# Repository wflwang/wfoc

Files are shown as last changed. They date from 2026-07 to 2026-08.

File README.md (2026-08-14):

# WFOC - 开源低成本高性能FOC电调





WFOC (WFL FOC) 是一款面向开源社区的低成本高性能无刷直流电机 FOC 控制器。项目参考 STM32 FOC 驱动、VESC 开源代码和 SimpleFOC，在国产 CIU32F003x5 (ARM Cortex-M0+) 上实现了完整的电机控制固件。

- 开源地址: https://github.com/wflwang/wfoc.git
- 邮箱: B5106D@Outlook.com

## 项目特点

- **低成本**: 采用国产 MCU (CIU32F003x5) 和 FD6288 栅极驱动，BOM 成本低
- **高性能**: 中断内全定点 Q16.16 运算（无浮点），20kHz PWM 电流环
- **双模式**: 同时支持 FOC 矢量控制和 BLDC 六步换相，可通过 `comm_mode` 配置切换
- **多观测器**: 滑模观测器 (SMO)、MXLEMMA 全阶观测器、MXV_Lambda 补偿、高频注入 (HFI)
- **VESC 风格协议**: 二进制 UART 协议，支持参数读写、实时遥测、高速流式打印
- **开源**: 硬件 (CERN-OHL-S v2) 和软件 (MIT) 全部开源

## 硬件架构

### 核心器件

| 器件 | 型号 | 封装 | 功能 |
|---|---|---|---|
| MCU | CIU32F003x5 | QFN-20 | 32位 ARM Cortex-M0+, 24MHz, 32KB Flash |
| 栅极驱动 | FD6288 | TSSOP-20 | 三相半桥驱动，内置自举二极管 |
| 运算放大器 | XOPA2333 | - | 2通道电流采样放大 |
| MOSFET | N-MOS | TO-252-2 | 3上 + 3下功率开关管 |

### 硬件特性

- **电源输入**: 10-48V DC
- **持续电流**: 20A（峰值 60A）
- **PWM 频率**: 8kHz-20kHz 可调（默认 20kHz）
- **电流采样**: 2路下桥臂电阻采样 (0.005R + 20x 运放)
- **通信接口**: UART (115200~921600) / PPM
- **保护功能**: 过流、过压、欠压、过温保护
- **调试接口**: SWD

### 引脚映射

引脚定义见 [board_config.h](software/config/board_config.h)，摘要：

| 功能 | 引脚 | 说明 |
|---|---|---|
| UART TX/RX | PC0 / PB5 | 串口通信 |
| PWM A 高/低 | PB2 / PB3 | A相上下管 |
| PWM B 高/低 | PC1 / PB7 | B相上下管 |
| PWM C 高/低 | PA1 / PA0 | C相上下管 |
| 电流采样 A/B | PB0 / PB1 | ADC CH0/CH1 |
| 相电压 U/V/W | PA3 / PA4 / PA5 | ADC CH3/CH4/CH5 |
| 母线电压 | PA7 | ADC CH7 |
| 温度 | PA6 | ADC CH6 |
| PPM 输入 | PB4 | TIM2 输入捕获 |

## 软件架构

### 目录结构

```
software/
├── main.c                  # 主程序入口（初始化与主循环）
├── interrupts.c            # 中断服务（ADC1 FOC环 / UART / PPM / SysTick）
├── Makefile                # 编译脚本
│
├── app/                    # 应用层
│   ├── app.c               # 状态机、安全监督、斜坡控制
│   ├── app_uart.c          # UART控制接口（VESC风格协议、实时遥测）
│   ├── app_ppm.c           # PPM脉冲解码
│   └── app_sound.c         # 电机发声
│
├── motor/                  # 电机控制核心
│   ├── mcpwm.c             # PWM后端桥接（duty/current/speed/position）
│   ├── observer.c          # 观测器（SMO / MXLEMMA / HFI + PLL）
│   ├── bldc.c              # BLDC六步换相（多种反电动势检测）
│   └── encoder.c           # 编码器接口
│
├── driver/mcu/             # MCU外设驱动
│   ├── adc.c               # ADC驱动（DMA多通道，偏置校准）
│   ├── pwm.c               # PWM驱动（TIM1三相中心对齐）
│   ├── uart.c              # UART驱动（环形缓冲收发）
│   ├── timer.c             # 定时器（PPM捕获/看门狗）
│   ├── gpio.c              # GPIO配置
│   ├── mcu_init.c          # 系统初始化（时钟/SysTick）
│   └── ciu32f003x.h        # MCU寄存器定义
│
├── conf/                   # 配置系统
│   ├── datatypes.h         # 核心数据类型（motor_state_t / mc_configuration_t）
│   ├── conf_default.c      # 默认参数
│   └── conf_general.c      # 配置管理（持久化接口）
│
├── config/                 # 编译时配置
│   ├── board_config.h      # 板级引脚映射与硬件参数
│   ├── hwconf.h            # 硬件目标选择（make HW=WFoc_V1）
│   └── fw_version.h        # 固件版本与功能开关
│
├── packet/                 # 通信协议
│   └── packet.c            # VESC风格帧封装（CRC16/CCITT）
│
├── startup/                # 启动文件
│   ├── linker.ld           # 链接脚本
│   └── startup_ciu32f003x.s# 启动汇编
│
└── util/                   # 工具库
    └── fixedpoint.c        # 定点数数学库（Q16.16, 三角函数, PI/PID, 陷波滤波）
```

### 数据流

```
ADC1 ISR (20kHz) ──► 电流采样 ──► Clarke ──► 观测器(角度/转速)
                                       │              │
                                       ▼              ▼
                                     Park ──► PI电流环 ──► 逆Park
                                                          │
                                                       SVPWM ──► TIM1 PWM
                                                          │
应用层 (main loop)                                        │
  app_process() ──► mcpwm_set_*() ──► foc_state.iq_set ───┘
  app_uart_process() ──► 遥测发送 ──► UART
```

### 核心功能实现状态

- [x] FOC 矢量控制（Clarke/Park/SVPWM/电流环PI）
- [x] BLDC 六步换相（ADC/比较器/过零检测 + 参数自学习）
- [x] 观测器（SMO / MXLEMMA / HFI + PLL 锁相环）
- [x] 定点数数学库（Q16.16，中断内无浮点）
- [x] VESC 风格 UART 协议（参数读写、固件版本、终端命令）
- [x] 实时遥测（3相电流、3相电压、转速、d/q轴等）
- [x] 高速流式打印（COMM_GET_VALUES_SELECTIVE + streaming）
- [x] ADC 偏置自校准（上电自动测量零电流偏移）
- [x] 安全监督（过流/过压/欠压/过温保护 + 故障状态机）
- [x] PPM 输入控制
- [x] 电机发声功能
- [ ] 速度闭环 PI（当前为前馈，参数已预留）
- [ ] 位置闭环控制
- [ ] 弱磁控制 / 过调制 / 陷波滤波（框架已建，待接入电流环）
- [ ] Flash 参数持久化（接口已定义，存储待实现）

## 编译环境

### 工具链安装

固件目标为 ARM Cortex-M0+，需要 `arm-none-eabi-gcc` 交叉编译工具链。

**Windows:**
1. 下载 [GNU Arm Embedded Toolchain](https://developer.arm.com/tools-and-software/open-source-software/developer-tools/gnu-toolchain/gnu-rm/downloads)
2. 解压并将 `bin` 目录加入系统 `PATH`
3. 安装 [Make for Windows](http://gnuwin32.sourceforge.net/packages/make.htm) 或使用 MSYS2

**Linux (Ubuntu/Debian):**
```bash
sudo apt install gcc-arm-none-eabi binutils-arm-none-eabi openocd
```

**macOS (Homebrew):**
```bash
brew install arm-gcc-bin openocd
```

### 验证工具链

```bash
arm-none-eabi-gcc --version    # 需要 10.x 或以上
arm-none-eabi-objcopy --version
openocd --version              # 烧录用
```

### 仿真环境（可选）

仿真在 PC 上运行，验证 FOC 定点算法，只需系统自带 GCC：

```bash
gcc --version    # Windows 可用 MinGW / MSYS2 的 gcc
```

## 编译步骤

### 编译固件

```bash
cd software
make              # 默认硬件目标 WFoc_V1
```

指定硬件目标与优化：
```bash
make HW=WFoc_V1   # 选择硬件版本（当前支持 V1）
make clean         # 清理构建产物
make size          # 查看 Flash/RAM 占用
make info          # 打印源文件列表和编译选项
```

编译成功后输出：
- `build/wfoc.elf` - ELF 可执行文件
- `build/wfoc.hex` - Intel HEX（烧录用）
- `build/wfoc.bin` - 二进制文件
- `build/wfoc.map` - 链接映射表

### 烧录固件

通过 ST-Link / J-Link + OpenOCD 烧录：
```bash
make flash        # 调用 openocd 烧录 build/wfoc.hex
```

也可手动烧录：
```bash
openocd -f interface/stlink.cfg -f target/ciu32f003x.cfg \
    -c "program build/wfoc.hex verify reset exit 0x08000000"
```

### 运行仿真

```bash
# Windows / Linux / macOS 均可
gcc -O2 -o simulation/sim_foc.exe simulation/sim_main.c software/util/fixedpoint.c -lm
./simulation/sim_foc.exe        # Linux/macOS
.\simulation\sim_foc.exe        # Windows PowerShell
```

仿真说明：
- 仿真使用**真实的定点数库** (`fixedpoint.c`)，与固件 ISR 完全相同的 Q16.16 运算
- `sim_main.c` 顶部 `SIM_USE_PERFECT_ANGLE` 开关：
  - `1` = 完美角度（验证 FOC 电流环本身），电机应加速到 400+ RPM
  - `0` = 观测器模式（验证 FOC + 观测器），验证角度估算

## 通信协议

### UART 接口

- 默认波特率: 115200（可通过参数调整为 921600 以支持高速打印）
- 格式: 8N1
- 协议: VESC 风格二进制帧

### 帧格式

```
短帧 (<256字节):  [0x02] [len] [payload...] [crc_hi] [crc_lo] [0x03]
长帧 (>=256字节): [0x03] [len_hi] [len_lo] [payload...] [crc_hi] [crc_lo] [0x03]
```
- `payload` = `[command] [data...]`
- CRC: CRC-16/CCITT (poly 0x1021, init 0xFFFF)

### 支持的命令

| 命令 | 名称 | 说明 |
|---|---|---|
| 0 | COMM_FW_VERSION | 获取固件版本与硬件名称 |
| 2 | COMM_GET_VALUES | 获取完整实时数据（含3相电流/电压/转速） |
| 4 | COMM_SET_DUTY | 设置占空比 (x1e5) |
| 5 | COMM_SET_CURRENT | 设置电流 (x1e3) |
| 6 | COMM_SET_CURRENT_BRAKE | 制动电流 (x1e3) |
| 7 | COMM_SET_RPM | 设置转速 ERPM |
| 8 | COMM_SET_POS | 设置位置 (x1e6) |
| 11 | COMM_GET_MCCONF | 读取电机配置 |
| 12 | COMM_SET_MCCONF | 写入电机配置 |
| 13/14 | COMM_GET/SET_APPCONF | 读取/写入应用配置 |
| 15 | COMM_DETECT_MOTOR_PARAM | 电机参数检测 |
| 17 | COMM_TERMINAL_CMD | 终端命令 (help/stop/restart/alive) |
| 18 | COMM_GET_VALUES_SELECTIVE | 高速选择性遥测（见下） |

### 实时遥测与高速打印

**完整遥测 (COMM_GET_VALUES)**：请求一次返回一帧，包含温度、3相电流、3相电压、d/q轴、占空比、转速、位置、母线电压、功率、故障码等。

**高速选择性遥测 (COMM_GET_VALUES_SELECTIVE)**：

上位机发送 `[mask:u32][rate_ms:u16]`，固件按位掩码只打包需要的字段，大幅减小数据包。`rate_ms > 0` 时开启**主动流式发送**（streaming），固件在主循环按设定间隔自动发送，无需反复请求。

字段掩码位定义（见 [datatypes.h](software/conf/datatypes.h)）：
```
bit 0-2:   IA / IB / IC     (3相电流)
bit 3-5:   VA / VB / VC     (3相电压)
bit 6-9:   ID / IQ / VD / VQ (d/q轴电流电压)
bit 10:    DUTY
bit 11:    SPEED (ERPM)
bit 12:    POSITION (rad)
bit 13:    VBUS
bit 14-15: TEMP_MOS / TEMP_MOT
bit 16:    POWER
```

示例：以 1ms 速率只打印 3相电流 + 3相电压 + 转速：
```
mask = IA|IB|IC|VA|VB|VC|SPEED = 0x208F
发送: COMM_GET_VALUES_SELECTIVE + [0x8F,0x20,0x00,0x00] + [0x01,0x00]
```

**实现原理**（高速打印关键）：
1. ADC 中断 (20kHz) 只采集数据存入 `motor_state` 变量，**不在中断中发串口**
2. 主循环中一次性组装数据包通过 UART 发送
3. streaming 模式避免请求-响应往返延迟
4. 提高波特率 (921600) 可进一步缩短发送时间

## 配置与调参

所有电机参数可通过 UART 在线调整（COMM_GET/SET_MCCONF），参数定义见 [datatypes.h](software/conf/datatypes.h) 的 `mc_configuration_t`，默认值见 [conf_default.c](software/conf/conf_default.c)。

关键参数：
- `comm_mode`: 0=FOC, 1=BLDC
- `observer_type`: 0=无, 1=SMO, 2=MXLEMMA, 3=MXV_Lambda, 4=HFI
- `motor_r / motor_l / motor_flux_linkage / motor_poles`: 电机参数
- `foc_current_kp / ki`: 电流环 PI 增益
- `foc_speed_kp / ki`: 速度环 PI 增益
- `l_max_current / l_max_speed / l_max_duty`: 限幅

## 贡献指南

欢迎任何形式的贡献！请遵循以下步骤：

1. Fork 本仓库
2. 创建功能分支 (`git checkout -b feature/your-feature`)
3. 提交代码 (`git commit -am 'Add some feature'`)
4. 推送到分支 (`git push origin feature/your-feature`)
5. 创建 Pull Request

## 许可证

本项目采用双重许可证：

| 部分 | 许可证 | 文件 |
|---|---|---|
| 软件代码 | MIT License | [LICENSE](LICENSE) |
| 硬件设计文件 | CERN-OHL-S v2 | [LICENSE-HARDWARE](LICENSE-HARDWARE) |

## 致谢

感谢以下开源项目的启发和参考：

- [VESC](https://github.com/vedderb/bldc) - BLDC 开源电调
- [SimpleFOC](https://github.com/simplefoc/Arduino-FOC) - 简易 FOC 库

## 联系方式

- 邮箱: B5106D@Outlook.com
- GitHub Issues: [提交 Issue](https://github.com/wflwang/wfoc/issues)

---

**免责声明**: 本项目仅供学习和研究使用。使用本项目造成的任何损失，作者不承担责任。请在使用前充分测试并确保安全。

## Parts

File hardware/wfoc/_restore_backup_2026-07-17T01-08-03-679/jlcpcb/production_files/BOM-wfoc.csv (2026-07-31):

Comment | Designator | Footprint | LCSC | Quantity
NMOS | Q1 | TO-252-2 |  | 1
105 | C5 | C_0603_1608Metric |  | 1
10R | R23 | R_0603_1608Metric |  | 1
100R | R13 | R_0603_1608Metric |  | 1
NMOS | Q3 | TO-252-2 |  | 1
10K | R32 | R_0603_1608Metric |  | 1
10K | R29 | R_0603_1608Metric |  | 1
NMOS | Q2 | TO-252-2 |  | 1
10R | R24 | R_0603_1608Metric |  | 1
10K | R28 | R_0603_1608Metric |  | 1
10K | R30 | R_0603_1608Metric |  | 1
20K 1% | R15 | R_0603_1608Metric |  | 1
104 | C7 | C_0603_1608Metric |  | 1
2.2K | R20 | R_0603_1608Metric |  | 1
103 | C19 | C_0603_1608Metric |  | 1
10R | R27 | R_0603_1608Metric |  | 1
10K 1% | R9 | R_0603_1608Metric |  | 1
10K | R44 | R_0402_1005Metric |  | 1
2K | R38 | R_0402_1005Metric |  | 1
0.1R | R18 | R_1206_3216Metric |  | 1
10R | R25 | R_0603_1608Metric |  | 1
104 | C14 | C_0603_1608Metric |  | 1
105 X7R | C17 | C_0603_1608Metric |  | 1
4.7K | R47 | R_0402_1005Metric |  | 1
47K | R40 | R_0805_2012Metric |  | 1
4.7K | R45 | R_0402_1005Metric |  | 1
10K | R33 | R_0603_1608Metric |  | 1
10K | R31 | R_0603_1608Metric |  | 1
20K 1% | R11 | R_0603_1608Metric |  | 1
47uH GSM0650-470-M | L1 | L_7.5x6.6mm |  | 1
470K | R17 | R_0603_1608Metric |  | 1
47K | R42 | R_0603_1608Metric |  | 1
104 | C6 | C_0603_1608Metric |  | 1
106 | C12 | C_0805_2012Metric |  | 1
20K 1% | R16 | R_0603_1608Metric |  | 1
10R | R26 | R_0603_1608Metric |  | 1
10R | R22 | R_0603_1608Metric |  | 1
470uf 80V | C9 | CP_Elec_10x12.5 |  | 1
2K | R36 | R_0402_1005Metric |  | 1
104 | C10 | C_0603_1608Metric |  | 1
100R | R14 | R_0603_1608Metric |  | 1
20K 1% | R12 | R_0603_1608Metric |  | 1
5819 | D1 | D_1206_3216Metric_Pad1.42x1.75mm_HandSolder |  | 1
TSSOP20 | U3 | TSSOP-20_4.4x6.5mm_P0.65mm |  | 1
2K | R37 | R_0402_1005Metric |  | 1
102 | C4 | C_0603_1608Metric |  | 1
20K | R19 | R_0603_1608Metric |  | 1
47K | R41 | R_0603_1608Metric |  | 1
102 | C3 | C_0603_1608Metric |  | 1
105 X7R | C16 | C_0603_1608Metric |  | 1
47K | R43 | R_0603_1608Metric |  | 1
103 | C20 | C_0603_1608Metric |  | 1
470uf 20V | C11 | CP_Radial_D10.0mm_P5.00mm_P7.50mm |  | 1
10R | R21 | R_0603_1608Metric |  | 1
2K | R35 | R_0603_1608Metric |  | 1
XOPA2333 | U2 | SOP-8_3.9x4.9mm_P1.27mm |  | 1
10K 1% | R7 | R_0603_1608Metric |  | 1
106 | C13 | C_0805_2012Metric |  | 1
~ | U1 | QFN-20-1EP_3x3mm_P0.4mm_EP1.5x1.5mm |  | 1
104 | C8 | C_0603_1608Metric |  | 1
6209 | U4 | SOT-23 |  | 1
105 X7R | C18 | C_0603_1608Metric |  | 1
4.7K | R46 | R_0402_1005Metric |  | 1
10uf 25V | C15 | C_0603_1608Metric |  | 1
10K NTC 4390K | TH1 | R_0603_1608Metric |  | 1
NMOS | Q5 | TO-252-2 |  | 1
0.005R 1% |  | R_2512_6332Metric |  | 0
0.005R 1% |  | R_2512_6332Metric |  | 0
NMOS | Q6 | TO-252-2 |  | 1
1K 1% | R10 | R_0603_1608Metric |  | 1
1K 1% | R5 | R_0603_1608Metric |  | 1
1K 1% | R8 | R_0603_1608Metric |  | 1
NMOS | Q4 | TO-252-2 |  | 1
1K 1% | R3 | R_0603_1608Metric |  | 1
0.005R 1% |  | R_2512_6332Metric |  | 0
0.005R 1% |  | R_2512_6332Metric |  | 0

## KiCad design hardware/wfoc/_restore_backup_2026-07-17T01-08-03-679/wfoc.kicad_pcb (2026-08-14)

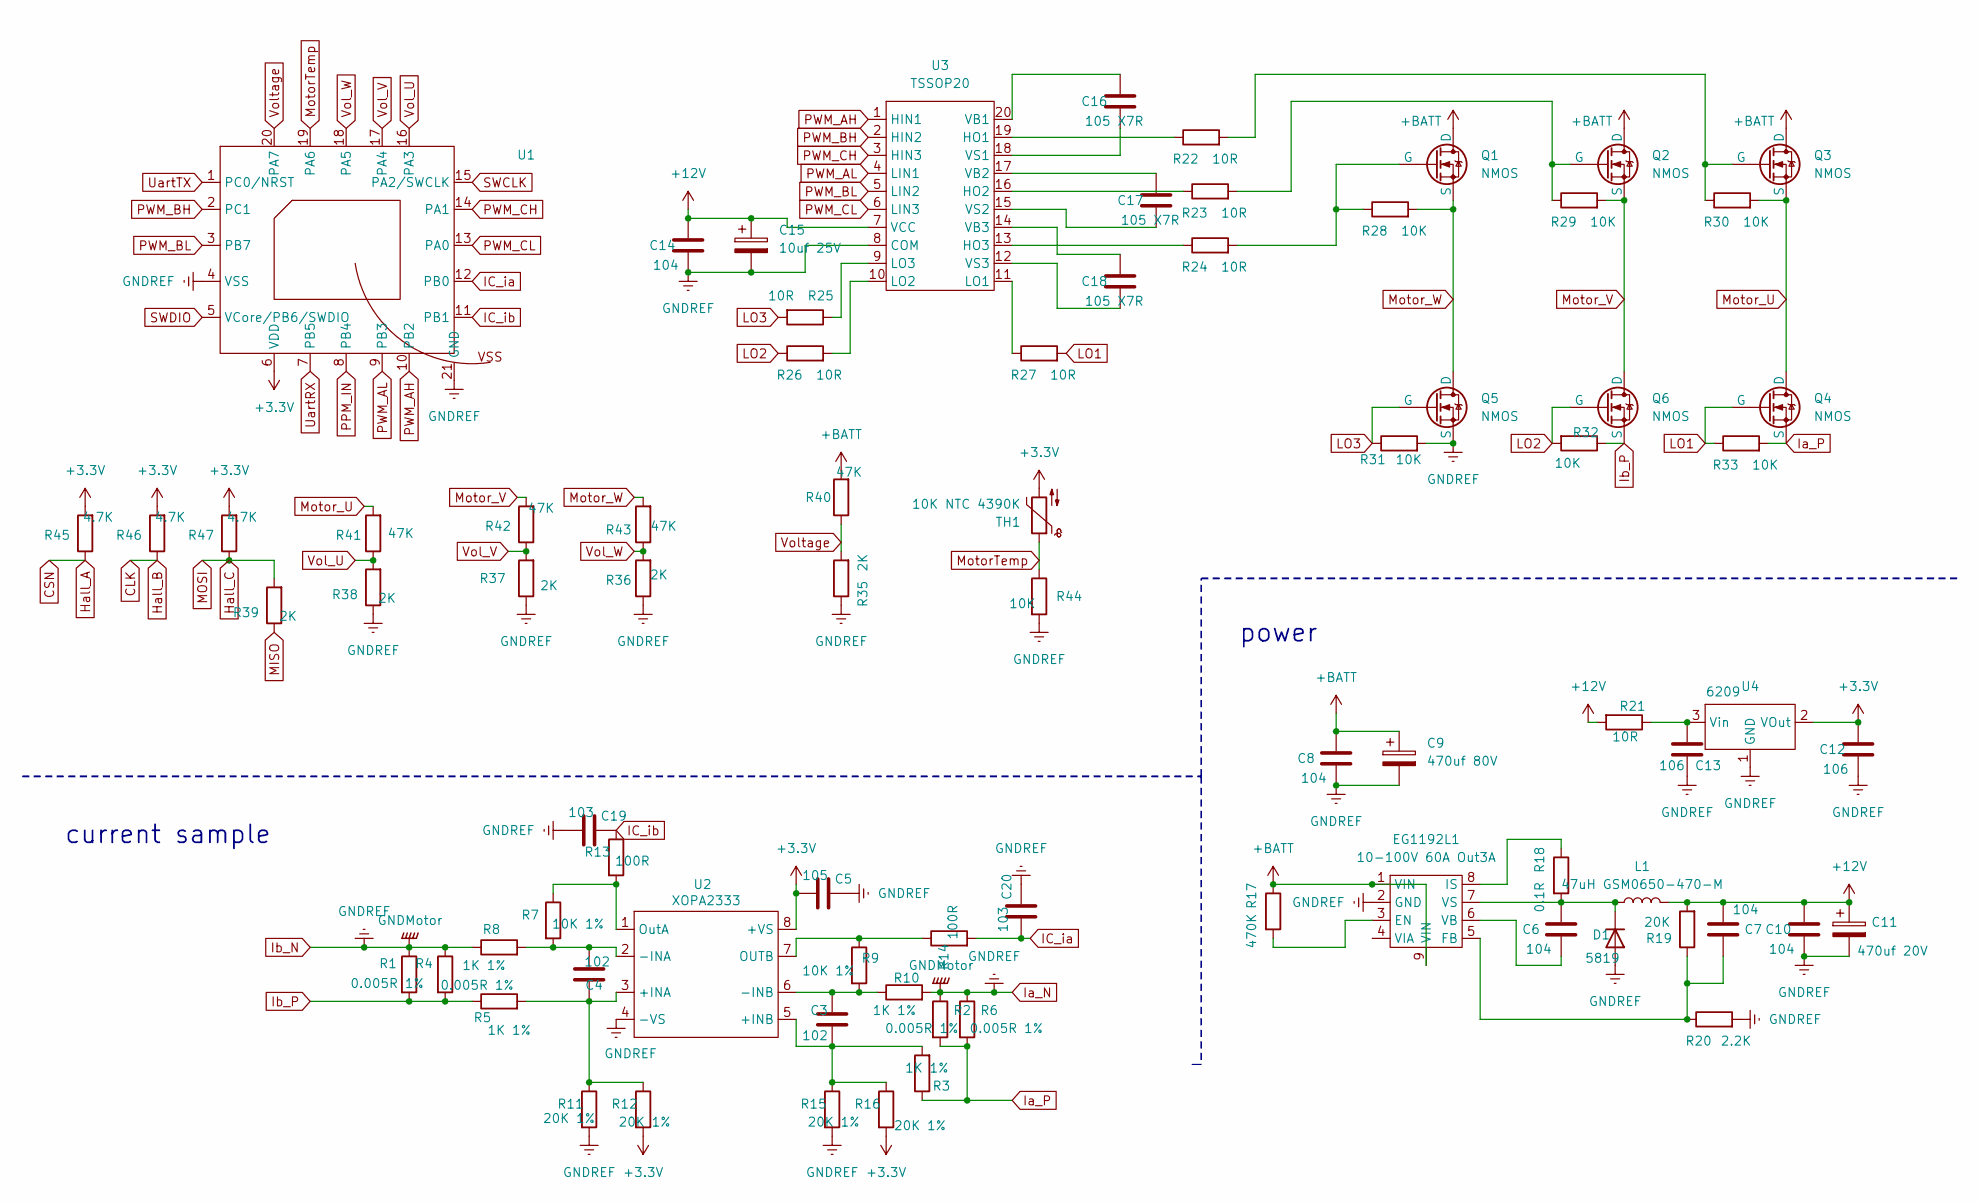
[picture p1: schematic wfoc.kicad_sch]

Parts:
C3, C4: 102; C_0603_1608Metric
C5: 105; C_0603_1608Metric
C6, C7, C8, C10, C14: 104; C_0603_1608Metric
C9: 470uf 80V; CP_Radial_D10.0mm_P7.50mm
C11: 470uf 20V; CP_Radial_D10.0mm_P7.50mm
C12, C13: 106; C_0805_2012Metric
C15: 10uf 25V; C_0603_1608Metric
C16, C17, C18: 105 X7R; C_0603_1608Metric
C19, C20: 103; C_0603_1608Metric
D1: 5819; D_1206_3216Metric_Pad1.42x1.75mm_HandSolder
EG1192L1: 10-100V 60A Out3A; SOP-8-1EP_6.0x4.9mm_P1.27mm_EP2.4x3.3mm
L1: 47uH GSM0650-470-M; L_7.5x6.6mm
Q1, Q2, Q3, Q4, Q5, Q6: NMOS; TO-252-2
R1, R2, R4, R6: 0.005R 1%; R_2512_6332Metric
R3, R5, R8, R10: 1K 1%; R_0603_1608Metric
R7, R9: 10K 1%; R_0603_1608Metric
R11, R12, R15, R16: 20K 1%; R_0603_1608Metric
R13, R14: 100R; R_0603_1608Metric
R17: 470K; R_0603_1608Metric
R18: 0.1R; R_1206_3216Metric
R19: 20K; R_0603_1608Metric
R20: 2.2K; R_0603_1608Metric
R21, R22, R23, R24, R25, R26, R27: 10R; R_0603_1608Metric
R28, R29, R30, R31, R32, R33: 10K; R_0603_1608Metric
R35: 2K; R_0603_1608Metric
R36, R37, R38, R39: 2K; R_0402_1005Metric
R40: 47K; R_0805_2012Metric
R41, R42, R43: 47K; R_0603_1608Metric
R44: 10K; R_0402_1005Metric
R45, R46, R47: 4.7K; R_0603_1608Metric
TH1: 10K NTC 4390K; R_0603_1608Metric
U1: QFN-20-1EP_3x3mm_P0.4mm_EP1.5x1.5mm
U2: XOPA2333; SOP-8_3.9x4.9mm_P1.27mm
U3: TSSOP20; TSSOP-20_4.4x6.5mm_P0.65mm
U4: 6209; SOT-23

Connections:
+3.3V: C5.1, C12.2, R12.2, R16.2, R45.2, R46.2, R47.2, TH1.2, U1.6 (VDD), U2.8 (+VS), U4.2 (VOut)
+12V: C7.1, C10.2, C11.1, C14.2, C15.1, L1.2, R19.2, R21.2, U3.7 (VCC)
+BATT: C8.2, C9.1, EG1192L1.1 (VIN), EG1192L1.9 (VIN), Q1.2 (D), Q2.2 (D), Q3.2 (D), R17.1, R40.2; also elsewhere on the board
IC_ia: C20.1, R14.2, U1.12 (PB0)
IC_ib: C19.2, R13.1, U1.11 (PB1)
Ia_N: C5.2, C8.1, C9.2, C10.1, C11.2, C12.1, C13.1, C14.1, C15.2, C19.1, C20.2, D1.2 (A), EG1192L1.2 (GND), Q5.3 (S), R1.1, R2.1, R4.1, R6.1, R8.1, R10.2, R11.2, R15.2, R20.2, R31.2, R35.1, R36.1, R37.1, R38.1, R44.2, U1.4 (VSS), U1.21 (GND), U2.4 (-VS), U3.8 (COM), U4.1 (GND); also elsewhere on the board
Ia_P: Q4.3 (S), R2.2, R3.1, R6.2, R33.2
Ib_P: Q6.3 (S), R1.2, R4.2, R5.1, R32.1
LO1: Q4.1 (G), R27.2, R33.1
LO2: Q6.1 (G), R26.1, R32.2
LO3: Q5.1 (G), R25.2, R31.1
MotorTemp: R44.1, TH1.1, U1.19 (PA6)
Motor_U: Q3.3 (S), Q4.2 (D), R30.2, R41.2
Motor_V: Q2.3 (S), Q6.2 (D), R29.2, R42.2
Motor_W: Q1.3 (S), Q5.2 (D), R28.2, R43.2
unnamed: C6.2, D1.1 (K), EG1192L1.7 (VS), L1.1, R18.2
unnamed: EG1192L1.3 (EN), R17.2
unnamed: C7.2, EG1192L1.5 (FB), R19.1, R20.1
unnamed: EG1192L1.8 (IS), R18.1
unnamed: C6.1, EG1192L1.6 (VB)
unnamed: Q1.1 (G), R24.2, R28.1
unnamed: Q2.1 (G), R23.2, R29.1
unnamed: Q3.1 (G), R22.2, R30.1
unnamed: C4.2, R5.2, R11.1, R12.1, U2.3 (+INA)
unnamed: C3.2, R3.2, R15.1, R16.1, U2.5 (+INB)
unnamed: C4.1, R7.2, R8.2, U2.2 (-INA)
unnamed: C3.1, R9.2, R10.1, U2.6 (-INB)
unnamed: R9.1, R14.1, U2.7 (OUTB)
unnamed: R7.1, R13.2, U2.1 (OutA)
unnamed: R22.1, U3.19 (HO1)
unnamed: R23.1, U3.16 (HO2)
unnamed: R24.1, U3.13 (HO3)
unnamed: R27.1, U3.11 (LO1)
unnamed: R26.2, U3.10 (LO2)
unnamed: R25.1, U3.9 (LO3)
unnamed: C16.2, U3.20 (VB1)
unnamed: C17.2, U3.17 (VB2)
unnamed: C18.2, U3.14 (VB3)
unnamed: C16.1, U3.18 (VS1)
unnamed: C17.1, U3.15 (VS2)
unnamed: C18.1, U3.12 (VS3)
unnamed: C13.2, R21.1, U4.3 (Vin)
PPM_IN: U1.8 (PB4)
PWM_AH: U1.10 (PB2), U3.1 (HIN1)
PWM_AL: U1.9 (PB3), U3.4 (LIN1)
PWM_BH: U1.2 (PC1), U3.2 (HIN2)
PWM_BL: U1.3 (PB7), U3.5 (LIN2)
PWM_CH: U1.14 (PA1), U3.3 (HIN3)
PWM_CL: U1.13 (PA0), U3.6 (LIN3)
SWCLK: U1.15 (PA2/SWCLK)
SWDIO: U1.5 (VCore/PB6/SWDIO)
UartRX: U1.7 (PB5)
UartTX: U1.1 (PC0/NRST)
Voltage: R35.2, R40.1, U1.20 (PA7); also elsewhere on the board

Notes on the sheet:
current sample
power

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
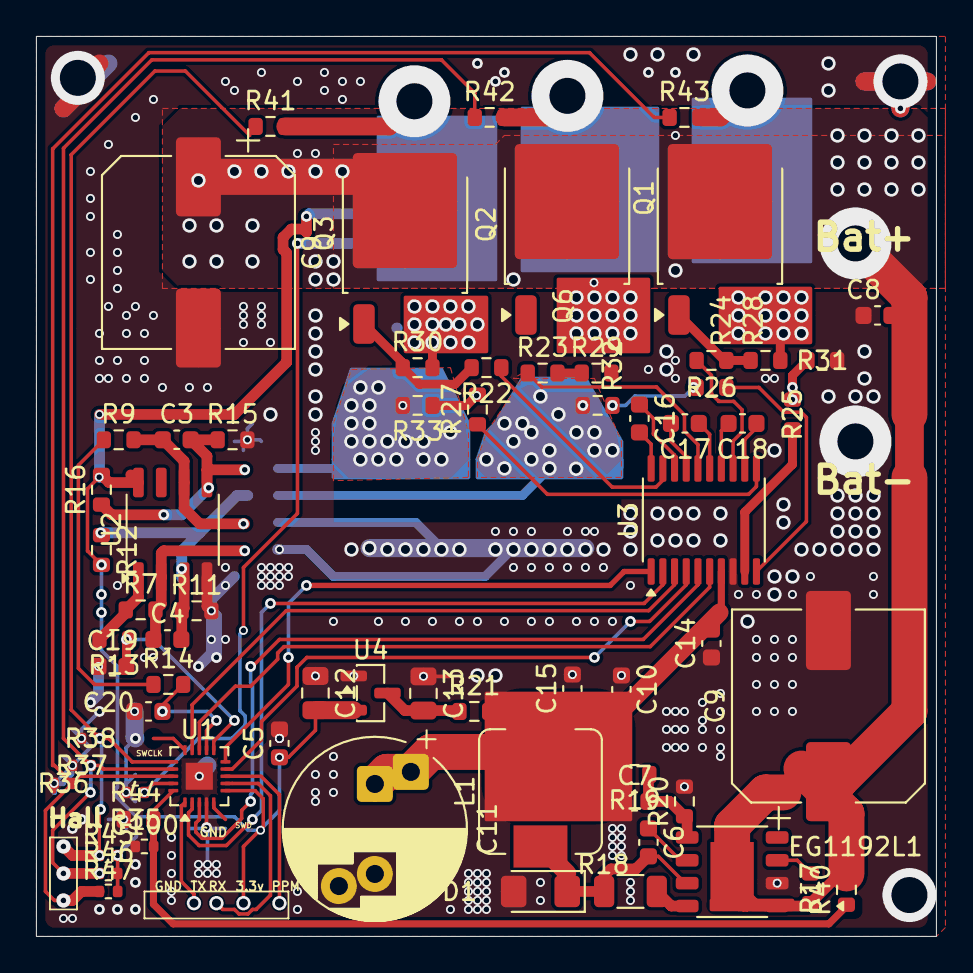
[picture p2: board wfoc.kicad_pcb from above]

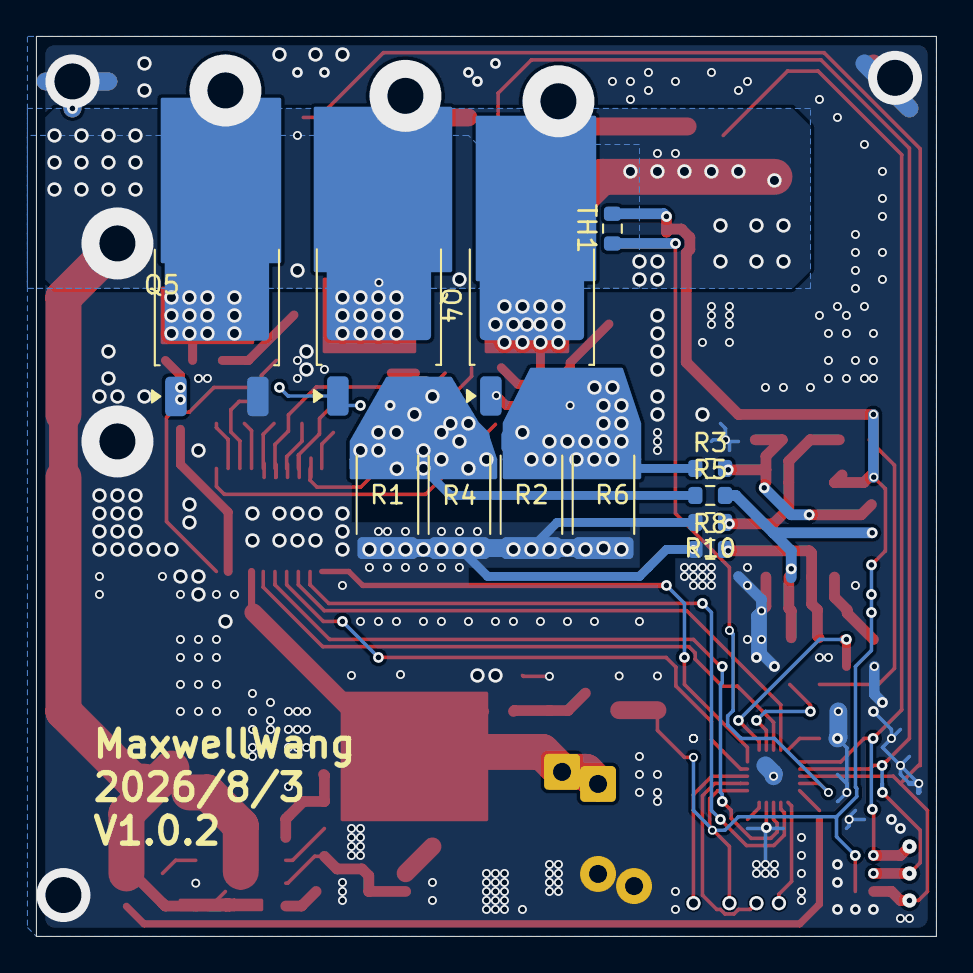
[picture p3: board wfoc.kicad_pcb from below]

Board: 2 copper layers, 50.0 x 50.0 mm, 79 parts (12 on the bottom side), 52 nets.

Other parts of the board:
C9#2: 470uf 80V; CP_Elec_10x12.5
C100: 104; R_0402_1005Metric

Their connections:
+BATT: C9#2.1; also elsewhere on the board
Ia_N: C9#2.2, C100.1; also elsewhere on the board
Voltage: C100.2; also elsewhere on the board

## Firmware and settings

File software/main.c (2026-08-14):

/*
 * main.c - WFOC Motor Controller Firmware Entry Point
 *
 * Initializes the MCU, peripherals, motor control subsystems and runs the
 * main application loop.  The real-time FOC current loop executes from the
 * ADC1 ISR (see interrupts.c); this main loop only handles the lower-rate
 * application layer (PPM / UART commands, duty / speed / position targets,
 * configuration management) and feeds the watchdog.
 *
 * WFOC (WFL FOC) - Open Source Low-Cost High-Performance FOC Controller
 * Copyright (c) 2026 wflwang
 * Licensed under MIT License
 */

#include <stdint.h>

#include "hwconf.h"
#include "fw_version.h"
#include "conf/datatypes.h"
#include "conf/conf_general.h"       /* mc_conf, app_conf, conf_general_init */
#include "motor/bldc.h"
#include "motor/observer.h"          /* observer_state_t, observer_init      */
#include "motor/foc.h"               /* foc_init, foc_update_temp_comp, ...  */
#include "app/app.h"                 /* app_init, app_process                */
#include "driver/mcu/flash.h"        /* Flash EEPROM emulation               */
#include "driver/mcu/ota.h"          /* OTA upgrade module                    */
#include "driver/mcu/spi.h"          /* SPI driver for future expansion      */

#include "driver/mcu/mcu_init.h"
#include "driver/mcu/adc.h"
#include "driver/mcu/gpio.h"
#include "driver/mcu/pwm.h"
#include "driver/mcu/uart.h"
#include "driver/mcu/timer.h"

/* ======================================================================== */
/* Forward Declarations - modules implemented elsewhere                      */
/* ======================================================================== */
extern void watchdog_feed(void);          /* driver/mcu/timer.c - IWDG kick  */

/* ======================================================================== */
/* Global Instances                                                          */
/* ======================================================================== */
/* mc_conf and app_conf are owned by conf_general.c (declared extern via
 * conf_general.h).  The real-time state singletons below are shared between
 * the application layer (main loop) and the ISR control loop.              */

motor_state_t        motor_state;         /* Real-time motor telemetry       */
foc_state_t          foc_state;           /* FOC current-loop internal state */
observer_state_t     observer_state;      /* Rotor observer state            */
bldc_state_t         bldc_state;          /* BLDC six-step runtime state     */

/* ======================================================================== */
/* FOC State Initialization                                                  */
/* ======================================================================== */
/* Delegates to foc_init() from motor/foc.c which configures the PI
 * controllers, LPFs, low-speed scheduler and temperature-compensated
 * motor parameters.  Float is used here (non-ISR context).               */
static void foc_init_state(foc_state_t *foc, mc_configuration_t *conf)
{
    foc_init(foc, conf);
}

/* ======================================================================== */
/* Main Entry Point                                                          */
/* ======================================================================== */
int main(void)
{
    /* --- Stage 1: MCU core (clock, flash, NVIC, SysTick) --- */
    mcu_init();

    /* --- Stage 2: Board pin muxing (ADC, PWM, UART, PPM, SWD) --- */
    gpio_config_board();

    /* --- Stage 3: Analog front-end (ADC + DMA, synchronized to TIM1) --- */
    adc_init();
    /* Measure zero-current ADC offsets while the power stage is still off.
     * This must happen before pwm_enable() so no current flows. */
    adc_calibrate_offsets();

    /* --- Stage 4: Power-stage timer (TIM1 3-phase center PWM) --- */
    pwm_init(PWM_FREQ_HZ);

    /* --- Stage 5: Communication (USART1) --- */
    uart_init(UART_BAUDRATE);

    /* --- Stage 6: PPM pulse-width capture (TIM2 input capture) --- */
    timer_init_ppm();

    /* --- Stage 7: Flash driver and EEPROM emulation ---
     * Must be initialized BEFORE conf_general_init() so that
     * stored parameters can be loaded from flash.            */
    flash_init();
    eeprom_init();

    /* --- Stage 8: Load persistent configuration from flash ---
     * EEPROM must be initialized (Stage 7) before this call.  */
    conf_general_init();

    /* --- Stage 9: Initialize FOC state (PI controllers, LPFs) --- */
    foc_init_state(&foc_state, &mc_conf);

    /* --- Stage 10: Initialize BLDC six-step commutation --- */
    bldc_init(&mc_conf);

    /* --- Stage 11: Application layer (PPM / UART / duty / speed modes) --- */
    app_init(&mc_conf, &app_conf);

    /* --- Stage 12: Rotor position observer (SMO / MXLEMMA / HFI) --- */
    observer_init(&observer_state, &mc_conf);

    /* --- Stage 13: OTA module initialization --- */
    ota_init();

    /* --- Stage 14: SPI initialization (reserved for remote/OTA) ---
     * SPI is initialized but not actively used. Ready for future
     * remote control receiver or wireless OTA module.
     * Note: MISO is externally connected to MOSI for half-duplex. */
    spi_init(SPI_CLK_DIV_16, SPI_MODE_0, 0);

    /* --- Stage 15: Start watchdog --- */
    watchdog_init();

    /* --- Enable PWM outputs (safe start, all duty cycles are zero) --- */
    pwm_enable();

    /* --- Enable global interrupts: ISRs are now live --- */
    mcu_irq_enable();

    /* ==================================================================== */
    /* Main Application Loop                                                */
    /* ==================================================================== */
    /* The FOC current loop runs at PWM rate from ADC1_IRQHandler; this loop
     * handles the slower application logic and feeds the watchdog.
     *
     * Slow-rate (non-ISR) FOC tasks scheduled here:
     *   - 1 kHz : startup ramp, speed loop, field weakening
     *   - 100 Hz: position loop, temperature compensation
     *                                                                       */
    uint32_t last_speed_tick = 0;      /* last tick for speed loop        */
    uint32_t last_temp_tick  = 0;      /* last tick for position/temp      */

    for (;;) {
        uint32_t now = s_tick_ms;  /* volatile read once per iteration  */

        /* --- 1 kHz FOC outer loops --- */
        if ((uint32_t)(now - last_speed_tick) >= 1U) {
            last_speed_tick = now;

            if (mc_conf.comm_mode != (uint8_t)COMM_MODE_BLDC) {
                /* Order matters:
                 * 1. Position loop (100 Hz effective, but called at 1kHz)
                 * 2. Startup ramp
                 * 3. Speed loop
                 * 4. Field weakening */

                /* Position loop (only if enabled) */
                foc_position_loop(&foc_state, &mc_conf);

                /* Startup ramp */
                foc_start_ramp_step(&foc_state, &mc_conf);

                /* Speed loop */
                foc_speed_loop(&foc_state, &mc_conf);

                /* Field weakening (adjusts id_set) */
                foc_field_weakening(&foc_state, &mc_conf);
            }
        }

        /* --- 100 Hz background tasks --- */
        if ((uint32_t)(now - last_temp_tick) >= 10U) {
            last_temp_tick = now;

            if (mc_conf.comm_mode != (uint8_t)COMM_MODE_BLDC) {
                /* Temperature compensation update */
                foc_update_temp_comp(&foc_state, &mc_conf,
                                     motor_state.temp_motor,
                                     motor_state.temp_mosfet);

                /* Update position measurement from observer
                 * This integrates speed to get position estimate */
                foc_state.pos_meas = motor_state.position;
            }
        }

        /* --- Application layer (PPM / UART / duty / speed modes) --- */
        app_process();
        watchdog_feed();
    }

    /* Unreachable */
    return 0;
}

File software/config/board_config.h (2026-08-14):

/*
 * board_config.h - WFOC V1 Board Pin Mapping
 *
 * Hardware: CIU32F003x5 (QFN-20, ARM Cortex-M0+)
 * Gate Driver: FD6288 (TSSOP-20, 3-phase half-bridge)
 * Current Sense: 0.005R shunt + XOPA2333 op-amp (2 channels)
 *
 * WFOC (WFL FOC) - Open Source Low-Cost High-Performance FOC Controller
 * Copyright (c) 2026 wflwang
 * Licensed under MIT License
 */

#ifndef BOARD_CONFIG_H
#define BOARD_CONFIG_H

/* ======================================================================== */
/* MCU Clock Configuration                                                   */
/* ======================================================================== */
#define MCU_CLK_HZ          24000000   /* 24 MHz internal RC */
#define ADC_CLK_HZ          12000000   /* ADC clock */
#define PWM_FREQ_HZ         20000      /* Default PWM frequency */
#define PWM_FREQ_MIN_HZ     8000       /* Min PWM frequency */
#define PWM_FREQ_MAX_HZ     20000      /* Max PWM frequency */

/* ======================================================================== */
/* Pin Definitions - from PCB net mapping                                   */
/* ======================================================================== */

/* --- UART --- */
#define UART_TX_PORT        GPIOC
#define UART_TX_PIN         0           /* PC0 (pin 1, shared with NRST) */
#define UART_RX_PORT        GPIOB
#define UART_RX_PIN         5           /* PB5 (pin 7) */
#define UART_BAUDRATE       115200

/* --- PWM (FD6288 Gate Driver) --- */
/* Phase A */
#define PWM_AH_PORT         GPIOB
#define PWM_AH_PIN          2           /* PB2 (pin 10) - A high */
#define PWM_AL_PORT         GPIOB
#define PWM_AL_PIN          3           /* PB3 (pin 9) - A low */

/* Phase B */
#define PWM_BH_PORT         GPIOC
#define PWM_BH_PIN          1           /* PC1 (pin 2) - B high */
#define PWM_BL_PORT         GPIOB
#define PWM_BL_PIN          7           /* PB7 (pin 3) - B low */

/* Phase C */
#define PWM_CH_PORT         GPIOA
#define PWM_CH_PIN          1           /* PA1 (pin 14) - C high */
#define PWM_CL_PORT         GPIOA
#define PWM_CL_PIN          0           /* PA0 (pin 13) - C low */

/* --- ADC Channels --- */
/* Current sensing (2 channels, phase A & B) */
#define ADC_IA_CHANNEL      ADC_CH0     /* PB0 (pin 12) - Phase A current */
#define ADC_IA_PORT         GPIOB
#define ADC_IA_PIN          0

#define ADC_IB_CHANNEL      ADC_CH1     /* PB1 (pin 11) - Phase B current */
#define ADC_IB_PORT         GPIOB
#define ADC_IB_PIN          1

/* Phase voltage sensing */
#define ADC_VOL_U_CHANNEL   ADC_CH3     /* PA3 (pin 16) - Phase U voltage */
#define ADC_VOL_V_CHANNEL   ADC_CH4     /* PA4 (pin 17) - Phase V voltage */
#define ADC_VOL_W_CHANNEL   ADC_CH5     /* PA5 (pin 18) - Phase W voltage */

/* Bus voltage sensing */
#define ADC_VBUS_CHANNEL    ADC_CH7     /* PA7 (pin 20) - Bus voltage */

/* Temperature sensing */
#define ADC_TEMP_CHANNEL    ADC_CH6     /* PA6 (pin 19) - Motor temperature */

/* --- PPM Input --- */
#define PPM_PORT            GPIOB
#define PPM_PIN             4           /* PB4 (pin 8) */
#define PPM_TIMER           TIM2

/* --- SPI (reserved for remote control / OTA) ---
 * Note: MISO is connected to MOSI externally for half-duplex */
#define SPI_SCK_PORT        GPIOA
#define SPI_SCK_PIN         2           /* PA2 (shared with SWCLK) */
#define SPI_MOSI_PORT       GPIOA
#define SPI_MOSI_PIN        3           /* PA3 */
#define SPI_MISO_PORT       GPIOA
#define SPI_MISO_PIN        4           /* PA4 (not used internally) */
#define SPI_CSN_PORT        GPIOA
#define SPI_CSN_PIN         5           /* PA5 (chip select, active low) */

/* --- SWD Debug --- */
#define SWDIO_PORT          GPIOB
#define SWDIO_PIN           6           /* PB6 (pin 5) */
#define SWCLK_PORT          GPIOA
#define SWCLK_PIN           2           /* PA2 (pin 15) - shared with SPI_SCK */

/* ======================================================================== */
/* Hardware Parameters                                                       */
/* ======================================================================== */

/* Power supply */
#define VBUS_MIN_V          10.0f       /* Min bus voltage */
#define VBUS_MAX_V          48.0f       /* Max bus voltage */
#define VBUS_WARN_V         50.0f       /* Over-voltage warning */

/* Current sensing */
#define SHUNT_RESISTOR      0.005f      /* 5mΩ shunt resistor */
#define OP_AMP_GAIN         20.0f       /* Op-amp gain (adjustable via R5/R8) */
#define CURRENT_MAX_A       60.0f       /* Max measurable current */
#define CURRENT_CONT_A      20.0f       /* Continuous current rating */

/* ADC reference */
#define ADC_VREF_V          3.3f        /* ADC reference voltage */
#define ADC_RESOLUTION      4096        /* 12-bit ADC */
#define ADC_VREF_INT        3300        /* mV for fixed-point calc */
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

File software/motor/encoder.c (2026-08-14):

/*
 * encoder.c - Hall Sensor / Encoder Interface (Stub)
 *
 * Implementation of the encoder API declared in encoder.h. On the WFOC V1
 * board there are no dedicated Hall-sensor GPIOs and no SPI encoder header,
 * so every hardware access is stubbed. The functions exist so that sensored
 * code paths link cleanly and can be enabled later by providing overrides
 * (or by extending this file) once the hardware is wired.
 *
 * The speed-differentiation and angle-offset logic is implemented here in
 * fixed-point so it is ready to use the moment real angle data is supplied.
 *
 * Target: ARM Cortex-M0+ (CIU32F003x5) - No FPU.
 * All ISR-time math uses Q16.16 fixed-point (no floating-point).
 *
 * WFOC (WFL FOC) - Open Source Low-Cost High-Performance FOC Controller
 * Copyright (c) 2026 wflwang
 * Licensed under the MIT License
 */

#include "encoder.h"
#include "config/hwconf.h"

/* ======================================================================== */
/* Module Configuration (single active encoder instance)                     */
/* ======================================================================== */
static encoder_config_t s_cfg;

/* Hall sector -> electrical angle (mid-sector) lookup.
 * 6 Hall states map to 6 electrical angles spaced 60 deg apart.
 * Index by raw 3-bit Hall pattern; entries for invalid patterns are 0.
 * Angles in angle_16 units (0..65535 = 0..360 deg).
 *
 * The exact mapping depends on Hall sensor placement. This is the canonical
 * 120-deg-spaced Hall table; it can be recalibrated via offset_angle / dir.
 */
static const uint16_t hall_angle_table[8] = {
       0,    /* 000 invalid */
       0,    /* 001 ->   0 deg */
   10923,    /* 010 ->  60 deg */
   21845,    /* 011 -> 120 deg */
   32768,    /* 100 -> 180 deg */
   43690,    /* 101 -> 240 deg */
   54613,    /* 110 -> 300 deg */
   65535,    /* 111 invalid */
};

/* ======================================================================== */
/* ISR Tick Period (seconds, Q16.16)                                          */
/* ======================================================================== */
/* Precomputed at init from PWM frequency: dt = 1 / FOC_LOOP_FREQ_HZ.
 * 20 kHz -> 50 us -> dt_q16 = FLOAT_TO_Q16(50e-6) = 3277. */
static q16_t s_dt_q16;

/* Speed low-pass filter coefficient. A light filter (tau ~ 2 ms) keeps the
 * differentiated speed usable for the speed loop without too much lag. */
static q16_t s_speed_alpha = 8192;   /* ~0.125 of new sample */

/* ======================================================================== */
/* Initialization                                                            */
/* ======================================================================== */

void encoder_init(encoder_state_t *enc, const encoder_config_t *cfg)
{
    if (enc == 0) {
        return;
    }

    /* Store configuration copy */
    if (cfg != 0) {
        s_cfg = *cfg;
    } else {
        s_cfg.type           = ENCODER_TYPE_NONE;
        s_cfg.hall_pole_pairs = 0;
        s_cfg.hall_dir       = +1;
        s_cfg.spi_cpr        = 0;
        s_cfg.inverted        = false;
        s_cfg.offset_angle    = 0;
    }

    /* Precompute ISR sample period (Q16.16 seconds).
     * FOC loop runs at FOC_LOOP_FREQ_HZ (= PWM_FREQ_HZ, default 20 kHz). */
    s_dt_q16 = FLOAT_TO_Q16(1.0f / (float)FOC_LOOP_FREQ_HZ);

    encoder_reset(enc);

    /* Stub: no hardware to detect. Mark as absent so the caller falls back
     * to the sensorless observer. A future platform override of
     * encoder_read_spi_absolute() / encoder_read_hall() should set
     * enc->present = true after a successful first transaction. */
    enc->type    = s_cfg.type;
    enc->present = false;
}

void encoder_reset(encoder_state_t *enc)
{
    if (enc == 0) {
        return;
    }

    enc->angle          = 0;
    enc->speed          = 0;
    enc->last_angle     = 0;
    enc->hall_state     = 0;
    enc->hall_last      = 0;
    enc->hall_ticks     = 0;
    enc->hall_period    = 0;
    enc->hall_speed_lpf = 0;
}

/* ======================================================================== */
/* Hardware Accessors (Stubs)                                                */
/* ======================================================================== */
/* On WFOC V1 there are no Hall GPIOs. Override these in a platform driver
 * when hardware is added. */

uint8_t encoder_read_hall(void)
{
    /* No Hall pins on WFOC V1 - always returns 0. */
    return 0;
}

uint16_t encoder_read_spi_absolute(void)
{
    /* No SPI encoder on WFOC V1 - always returns 0. */
    return 0;
}

/* ======================================================================== */
/* Sampling                                                                  */
/* ======================================================================== */
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

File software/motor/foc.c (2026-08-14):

/*
 * foc.c - FOC Core Controller (Q16.16 Fixed-Point Implementation)
 *
 * Provides the complete FOC control algorithm used by the WFOC firmware.
 *
 * ISR time budget target: < 4us @ 20 kHz on Cortex-M0+ (CIU32F003x5).
 *
 * WFOC (WFL FOC) - Open Source Low-Cost High-Performance FOC Controller
 * Copyright (c) 2026 wflwang
 * Licensed under the MIT License
 */

#include <stdint.h>
#include <string.h>
#include "foc.h"
#include "conf/datatypes.h"
#include "motor/observer.h"
#include "config/hwconf.h"

/* ======================================================================== */
/* Precomputed Q16 constants (computed once in foc_init)                    */
/* ======================================================================== */

/* 1/sqrt(3) for Clarke transform beta axis.  Already defined in interrupts.c,
 * but we keep a local copy here for clarity / if this module is used alone.*/
#define FOC_1_SQRT3_Q16   ((q16_t)37837)  /* 1/sqrt(3) in Q16.16 */

/* rad/s -> ERPM conversion factor:
 *   1 rad/s = 60/(2*pi*poles) ERPM
 * For poles=7: factor = 60/(2*pi*7) ~= 1.364
 * We precompute as Q16.16 per-pole.  User multiplies by 1/poles.            */
#define RADPS_TO_RPM_PER_POLE  ((q16_t)891929)  /* 60/(2*pi) in Q16.16 */

/* ======================================================================== */
/* foc_init                                                                  */
/* ======================================================================== */
void foc_init(foc_state_t *foc, mc_configuration_t *conf)
{
    memset(foc, 0, sizeof(*foc));

    /* Current loop PI (d-axis and q-axis use same gains by default). */
    q16_pi_init(&foc->pid_id,
                FLOAT_TO_Q16(conf->foc_current_kp),
                FLOAT_TO_Q16(conf->foc_current_ki),
                FLOAT_TO_Q16(conf->l_max_current),
                FLOAT_TO_Q16(conf->l_max_duty));

    q16_pi_init(&foc->pid_iq,
                FLOAT_TO_Q16(conf->foc_current_kp),
                FLOAT_TO_Q16(conf->foc_current_ki),
                FLOAT_TO_Q16(conf->l_max_current),
                FLOAT_TO_Q16(conf->l_max_duty));

    /* Speed loop PI.  Output is Iq (A), input is speed error (ERPM).     */
    q16_pi_init(&foc->pid_speed,
                FLOAT_TO_Q16(conf->foc_speed_kp),
                FLOAT_TO_Q16(conf->foc_speed_ki),
                FLOAT_TO_Q16(conf->l_max_current),
                FLOAT_TO_Q16(conf->l_max_current));

    /* Low-pass filters. */
    foc->lpf_id.alpha_q16 = FLOAT_TO_Q16(conf->foc_current_filter);
    foc->lpf_id.y         = 0;
    foc->lpf_iq.alpha_q16 = FLOAT_TO_Q16(conf->foc_current_filter);
    foc->lpf_iq.y         = 0;
    foc->lpf_speed.alpha_q16 = FLOAT_TO_Q16(0.10f);   /* 100 ms filter on speed */
    foc->lpf_speed.y         = 0;
    foc->lpf_temp.alpha_q16  = FLOAT_TO_Q16(0.01f);   /* very slow temp filter  */
    foc->lpf_temp.y          = 0;

    /* Temperature-compensated motor parameters (initial = nominal).      */
    foc->r_q16   = FLOAT_TO_Q16(conf->motor_r);
    foc->l_q16   = FLOAT_TO_Q16(conf->motor_l);
    foc->psi_q16 = FLOAT_TO_Q16(conf->motor_flux_linkage);

    /* Low-speed gain scheduling: start at unity gain. */
    foc->cur_kp_scale  = Q16_ONE;
    foc->cur_ki_scale  = Q16_ONE;
    foc->low_speed_active = 0;

    /* Precompute low-speed thresholds in Q16.16 (for ISR). */
    foc->ls_thr_q16   = FLOAT_TO_Q16(conf->foc_low_speed_thr);
    foc->ls_hyst_q16  = FLOAT_TO_Q16(conf->foc_low_speed_hyst);
    foc->ls_boost_q16 = FLOAT_TO_Q16(conf->foc_low_speed_boost);
    foc->ls_alpha_q16 = FLOAT_TO_Q16(0.05f);

    /* BEMF feedforward scaling (speed-dependent).
     *   at |ERPM| < thr     -> bemf_scale = boost
     *   at |ERPM| > full     -> bemf_scale = 1.0
     *   linear ramp in between.                                    */
    foc->bemf_comp_thr_q16  = FLOAT_TO_Q16(conf->foc_bemf_comp_thr);
    foc->bemf_comp_full_q16  = FLOAT_TO_Q16(conf->foc_bemf_comp_full);
    foc->bemf_comp_boost_q16 = FLOAT_TO_Q16(conf->foc_bemf_comp_boost);
    foc->bemf_scale_q16      = foc->bemf_comp_boost_q16;  /* start low */

    /* Startup current ramp precomputed constants.
     * foc_start_ramp_ms ms / 1kHz = ramp_ticks.                    */
    {
        float ramp_ms = conf->foc_start_ramp_ms;
        uint16_t ticks = (uint16_t)(ramp_ms + 0.5f);   /* ms -> 1kHz ticks */
        if (ticks < 2) ticks = 2;
        foc->start_ramp_ticks_max_q16 = INT_TO_Q16((int32_t)ticks);
    }
    foc->start_speed_thr_q16   = FLOAT_TO_Q16(conf->foc_start_speed_thr);
    foc->start_step_current_q16 = FLOAT_TO_Q16(conf->foc_start_step_current);
    foc->start_ramp_active      = 0;
    foc->start_ramp_ticks      = 0;
    foc->start_iq_current      = 0;
    foc->start_iq_target       = 0;
    foc->start_iq_step_q16     = 0;

    /* PLL effective gains start at nominal. */
    foc->pll_kp_eff = FLOAT_TO_Q16(conf->observer_pll_kp);
    foc->pll_ki_eff = FLOAT_TO_Q16(conf->observer_pll_ki);

    /* Pre-compute base Q16 gains used by the ISR scheduler to avoid
     * FLOAT_TO_Q16 calls inside the ADC ISR.                        */
    foc->cur_kp_base_q16 = FLOAT_TO_Q16(conf->foc_current_kp);
    foc->cur_ki_base_q16 = FLOAT_TO_Q16(conf->foc_current_ki);

    foc->pll_kp_normal_q16 = FLOAT_TO_Q16(conf->observer_pll_kp);
    foc->pll_ki_normal_q16 = FLOAT_TO_Q16(conf->observer_pll_ki);
    foc->pll_kp_low_q16    = FLOAT_TO_Q16(conf->observer_pll_kp_low);
    foc->pll_ki_low_q16    = FLOAT_TO_Q16(conf->observer_pll_ki_low);

    /* Precompute reciprocals for ISR usage.
     * 1/thr in Q16.16 = Q16_ONE / thr.  Done once at init (non-ISR). */
    if (foc->ls_thr_q16 > 0) {
        foc->ls_thr_inv_q16 = Q16_DIV(Q16_ONE, foc->ls_thr_q16);
    } else {
        foc->ls_thr_inv_q16 = Q16_ONE;
    }

    {
        q16_t span = foc->bemf_comp_full_q16 - foc->bemf_comp_thr_q16;
        if (span > 0) {
            foc->bemf_span_inv_q16 = Q16_DIV(Q16_ONE, span);
        } else {
            foc->bemf_span_inv_q16 = Q16_ONE;
        }
    }

    /* PLL ki per ISR step = ki (1/s) / loop_freq_hz.
     * Precomputed here so the ISR never divides by FOC_LOOP_FREQ_HZ. */
    {
        int32_t freq = (int32_t)FOC_LOOP_FREQ_HZ;
        if (freq < 1) freq = 1;
        foc->pll_ki_per_step_normal_q16 =
            (q16_t)(((int64_t)foc->pll_ki_normal_q16 / freq));
        foc->pll_ki_per_step_low_q16 =
            (q16_t)(((int64_t)foc->pll_ki_low_q16 / freq));
    }

    /* Feedforward Iq start = 0. */
    foc->iq_ff = 0;
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

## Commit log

2026-07-02 my foc sch first version
    [wfoc.kicad_pcb, wfoc.kicad_sch]
2026-07-05 修改PCB板连线
    [BOM-wfoc.csv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]
2026-07-09 提交最新的readme 和hardware改动
    [wfoc.kicad_sch]
2026-07-09 save last vesion
    [wfoc.kicad_pcb, wfoc.kicad_sch]
2026-07-09 基本画好 还有些信号线没有连上了
    [wfoc.kicad_pcb, wfoc.kicad_sch]
2026-07-19 提交最后板子修改版本
    [BOM-wfoc.csv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]
2026-07-19 updata new pcb
2026-07-24 修改好了 把所有规则删掉就可以正常铺铜了
    [BOM-wfoc.csv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]
2026-07-25 save gitignore file
    [BOM-wfoc.csv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]
2026-07-31 过大电流线加粗处理
    [wfoc.kicad_pcb, wfoc.kicad_sch]
2026-07-31 修改PCB大小和 电流采样开尔文线
    [BOM-wfoc.csv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]
2026-08-14 vesc 风格的第一个版本程序
    [wfoc.kicad_pcb]
